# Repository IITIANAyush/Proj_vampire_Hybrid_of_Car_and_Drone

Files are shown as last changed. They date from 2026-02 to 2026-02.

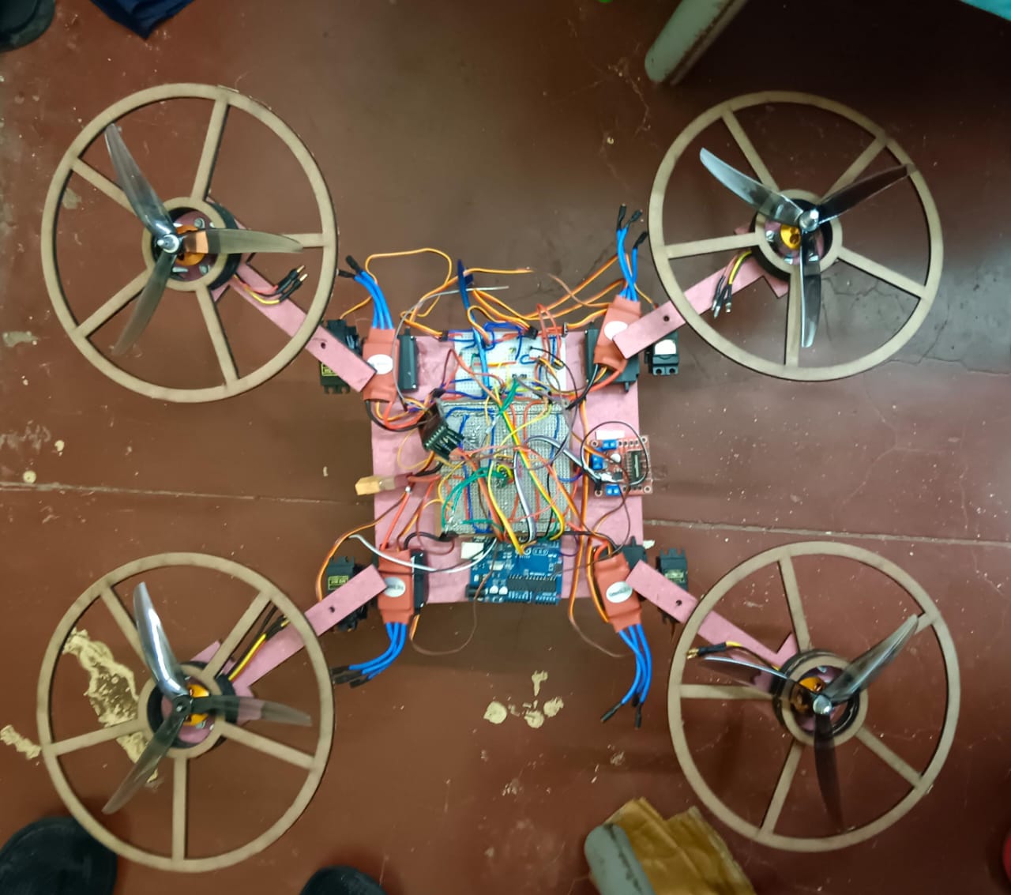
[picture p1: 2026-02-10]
Media/Assembly/Assembly_in_Drone_Mode2.jpg

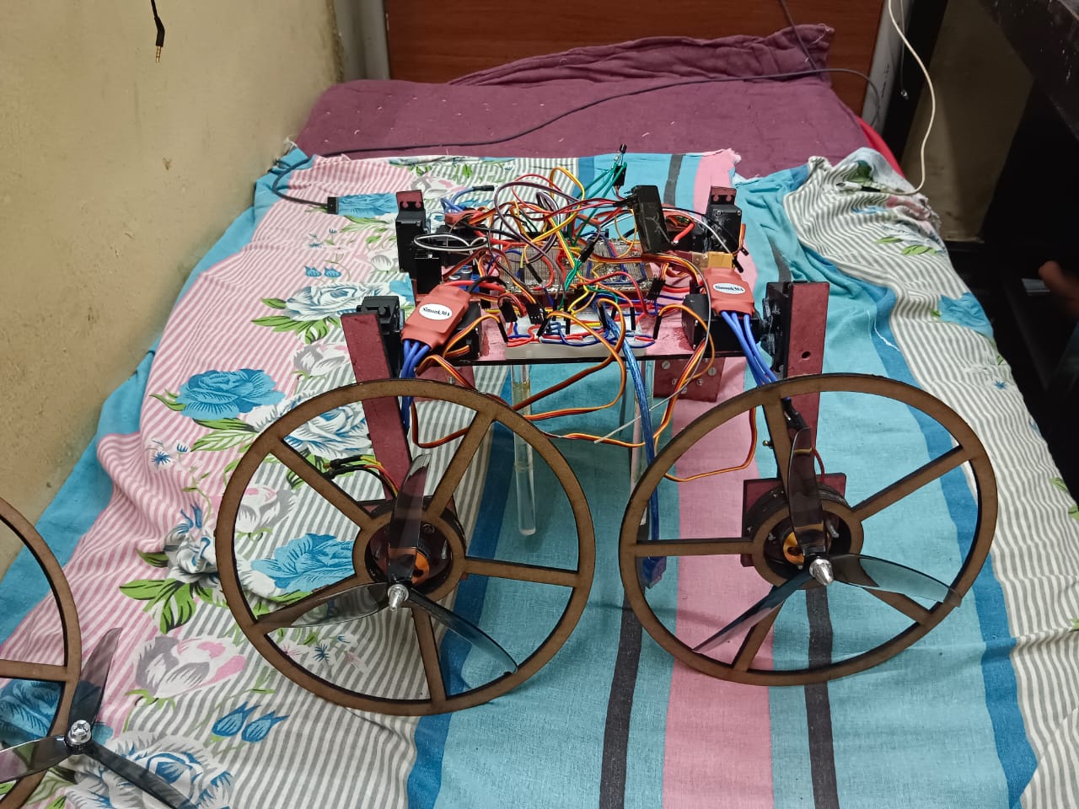
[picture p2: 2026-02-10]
Media/Assembly/Assembly_in_car_mode2.jpg

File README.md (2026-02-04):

# 🚀 Transformable Aerial–Ground Robot  
### Institute Technical Summer Project (ITSP)

This project presents the design and development of a **hybrid robot capable of operating both as a ground vehicle and as a quadcopter drone**. The system mechanically transforms between driving and flying configurations using servo-actuated arms.

Inspired by research in **reconfigurable robotics** from leading institutions like MIT, this project explores **multi-modal mobility**, where a single robot can adapt its structure to traverse different terrains and environments.

---

## 🎯 Project Objectives

- Design a robot that can **drive on the ground and fly in the air**
- Develop a **mechanical transformation system**
- Integrate **aerial and ground mobility** into one platform
- Build a **low-cost student prototype** using accessible components

---

## 🧩 System Overview

| Subsystem | Description |
|---|---|
| 🛞 Ground Mobility | Differential drive wheel system using DC motors |
| 🚁 Aerial Mobility | Quadcopter propulsion using brushless motors + ESCs |
| 🔁 Transformation Mechanism | Servo-actuated rotating arms |
| 🎮 Control Unit | Arduino-based control system |
| 🔋 Power System | LiPo battery powering motors and control electronics |

---

## 🛠 Hardware Design

The robot frame and transformation mechanism were custom-designed and iterated through multiple prototypes.

**Key Mechanical Features**
- Rotating arms that reposition wheels into propeller arms
- Lightweight structural frame
- Integrated motor mounting system

📁 See `Hardware/3D_Models/` for CAD files  
📁 Assembly visuals available in `Hardware/Assembly_Images/`

---

## 🔌 Electronics System

The electronics architecture manages both locomotion modes and the transformation system.

**Main Components**
- Arduino Uno
- Brushless motors + ESCs
- DC drive motors
- Servo motors for transformation
- RF transmitter & receiver module

📁 Circuit diagrams → `Electronics/Circuit_Diagrams/`  
📁 Wiring layouts → `Electronics/Wiring_Layouts/`  
📁 Tinkercad designs → `Electronics/Tinkercad_Designs/`

---

## 💻 Software Architecture

The control software is divided by functional modules.

| Module | Function |
|---|---|
| Flight Controller | Stabilization and motor control for drone mode |
| Car Mode Control | Wheel motor control for ground movement |
| Mode Switching | Handles transformation between car and drone |
| ESC Calibration | Calibration routine for brushless ESCs |

📁 All Arduino programs are available in the `Software/` directory.

---

## 🔁 Transformation Mechanism

The robot transitions between modes using servo-driven arms:

**Car Mode ➝ Drone Mode**
1. Arms rotate outward  
2. Wheels reposition to become landing supports  
3. Propellers align for flight  

**Drone Mode ➝ Car Mode**
1. Arms fold inward  
2. Wheels align for ground contact  
3. Drive motors engage  

This allows the robot to adapt based on terrain and task requirements.

---

## 🧪 Simulations & Testing

Early-stage circuit and control logic were tested using simulation tools before hardware implementation.

📁 Simulation files available in `Simulations/`

---

## 🎥 Demonstrations

Project demonstration videos showing transformation and testing:

📁 `Media/Transformation_Videos/`

---

## 📘 Documentation

Complete design explanation and project presentation:

📁 `Documentation/ITSP_Presentation.pdf`

---

## ⚠️ Safety Notice

This is a student-built prototype. Flight tests were conducted in controlled environments with safety precautions. The system is not intended for commercial or outdoor autonomous operation.

---

## 👨‍🔬 Developed Under

**Institute Technical Summer Project (ITSP)**  
Student Engineering Research Initiative

---

## 📌 Future Improvements

- Autonomous stabilization using IMU + PID control  
- Lightweight composite frame  
- Automatic terrain-based mode switching  
- Onboard camera for aerial surveillance  

---

## 🤝 Acknowledgment

This project was inspired by ongoing research in **transformable and reconfigurable robotics**, demonstrating how adaptable robots can enhance mobility in complex environments.

---

**⭐ If you find this project interesting, consider starring the repository!**

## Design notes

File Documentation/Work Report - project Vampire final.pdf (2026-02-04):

# Work Report - project Vampire

## Ayush Bhaskar- Dawar Jyoti Deka -Rahul Singh- Aman Raj

## ** dropped ideas and discussions has not been included in work report

Our Project Vampire integrates advanced aerial dynamics with sophisticated terrestrial navigation, utilising a unique orientation mechanism to transition from a car-like structure to a drone. The design addresses complex challenges in part integration, circuit design, and microprocessor coordination, ensuring seamless operation across diverse environments.

15th May to 6th June -
a. Decided upon the project idea , decided and built the team started ideating on the design and Abstract.
b. Started the technical research , digged research papers and similar projects that other universities are working on and found resources relevant to our project.
c. Drew out a basic design and made a basic working CAD model of the Chassis,decided the components like strong Servos , BLDC Motors for propellers and DC motors for Wheels , decided to make it a two wheel drive bot and Arduino , Motor Driver and electronic Speed Controllers for its technical performance as a drone.
d. Decided and designed the systems of control and command, parallelly worked on the mathematical analysis of the forces , weight and torques that the parts of the decided model might face and decided the specs of the components (Both mechanical and electrical ) on the basis of that.

7th June to 13th June i.e June Second Week -
a. Decided the control system we will be using to control the vehicle. Flysky FSi6a transmitter- receiver set.
b. Designed simulations and circuit for arm motion in tinkercad.
c. An online calculator or simulator ecal , and rc plane online was used to calculate the thrust generated and other information.
d. Number of servos and deciding their orientation for arm movement.
e. Orderning of some electrical parts.
f. Code for arm rotation part ready with tests on real models.

14th June to 20th June i.e third Week-
a. 3d sample model of drone with motion study formed.(in videos section of link)
b. Code for drone and other functions are ready to be uploaded on respective electronic controllers.
c. Decided the material to be used for the drone body , and laser cut it .

d. Soldered the pcb board to form a power distribution board and installed sensor and arduino nano on it.

21st June to 27th June i.e fourth Week-
a. Used epoxy glue to stick servos and power distribution board to the main chassis.
b. Decided the structure of the arm , decided to use double layered wood, with a 4mm hole in the outer side and servo horn cut on the inner part to fix it with a servo motor.
c. Made the model and tested it with code.
d. Building all connections on a breadboard.

28th June to 4th July i.e fifth Week -
a. Discussion on stand.
b. Discussion on concentric motion of tyre and propeller with different driving motors and without interference.
c. Usage of acrylic rods as stand to reduce stress on servo while changing mode and protecting battery
d. Buying materials(wires, glue,ball bearing)

5th July to 11th July i.e sixth Week -
a. Discussion and brainstorming on creating concentric independent motion for tyre and propeller.
b. Laser cutting of sample parts which will be used as tyres.
c. Buying material for creating tyre and belt driven motion for tyre.

12th July to 18th July i.e seventh Week-
a. Finalizing the design and making a 3d model for the coaxial tyre system.
b. Working on a Work report for the final review meeting.

19th July to 20th July i.e eight Week-
a. Worked on work report.
b. Buying material for laser cutting the tyre with spokes and coaxial system to be used in vehicle.

The drive link with all screenshots , video of simulations, code, 3d models and bill : https://drive.google.com/drive/folders/1VQIHgKka7rpowqe24aDche_vBiRUvNMP?usp=share_li nk (https://drive.google.com/drive/folders/1VQIHgKka7rpowqe24aDche_vBiRUvNMP?usp=share_link)

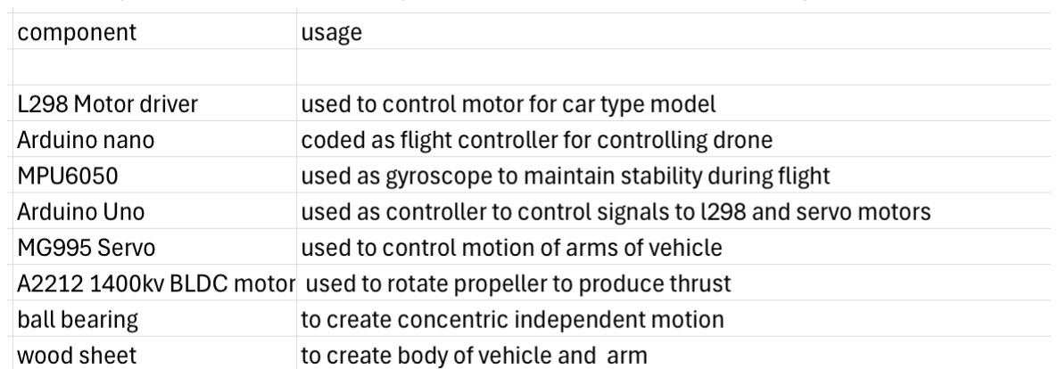
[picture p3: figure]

Some key components with key features to be used in our project are as listed

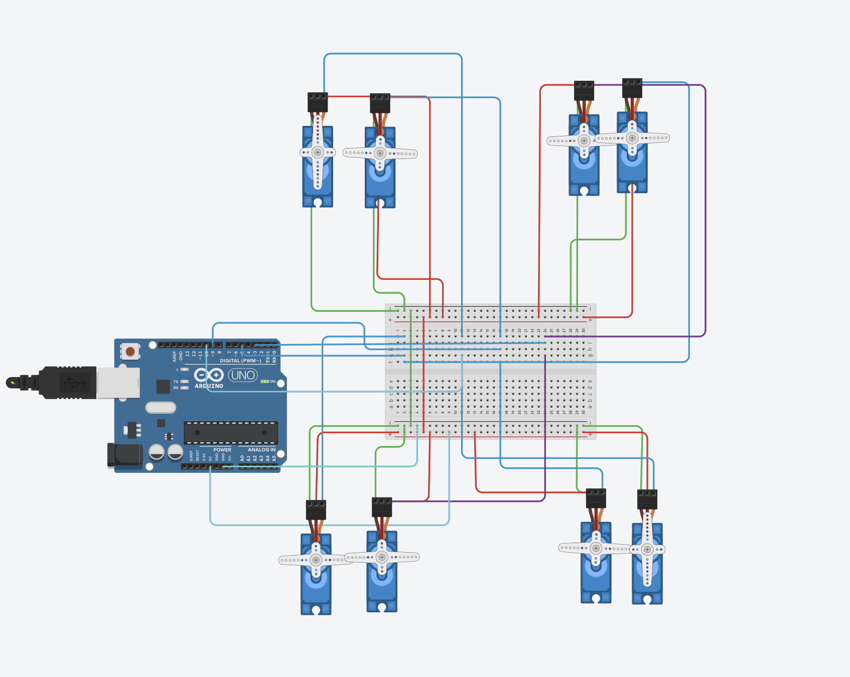
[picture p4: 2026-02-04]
Electronics/connection for controlling servo.png

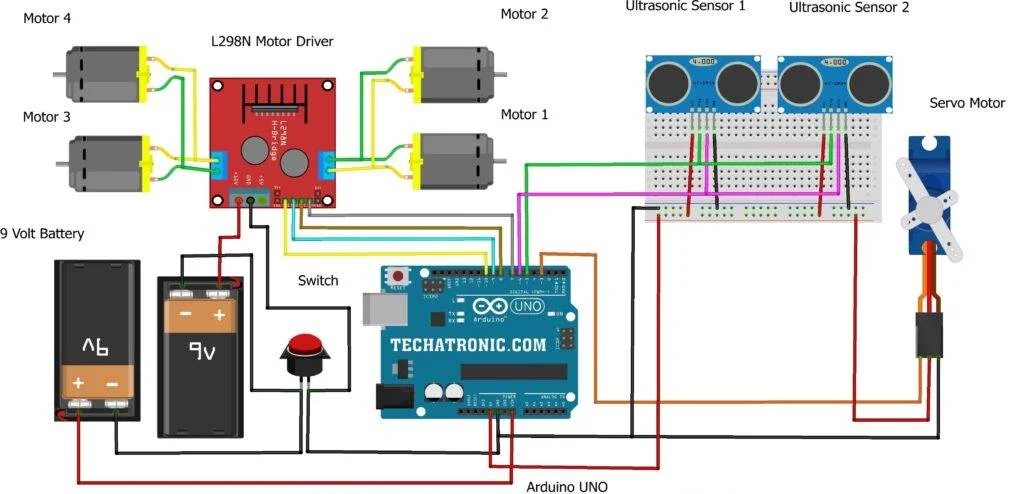
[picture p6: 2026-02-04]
Electronics/connection for driving motor using uno_ reference.webp

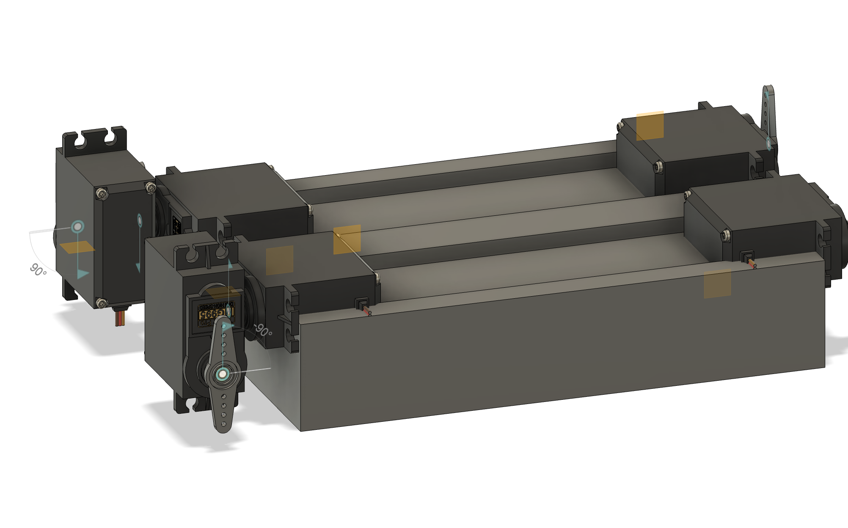
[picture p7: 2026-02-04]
Media/Simulation/deciding the servo orientation.png

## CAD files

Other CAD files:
Hardware/3d models/deciding the arm and placement of propellers with tyre rim.f3z
Hardware/3d models/deciding the servo orientation.f3z
Hardware/3d models/initial ideas and model.f3d
Hardware/3d models/wheel belt drive systum.f3z
Hardware/3d models/wheel_model v2.f3d

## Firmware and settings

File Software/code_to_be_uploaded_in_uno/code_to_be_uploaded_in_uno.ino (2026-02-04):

#include <Servo.h>

// Define servo objects
Servo chassy1;
Servo wheel1;
Servo chassy2;
Servo wheel2;

// Position variables
int poschassy1; // Position of servo of chassy
int poswheel1; // Position of servo of wheel

// State variables
bool previousstate = 0;
bool currentstate;

double ch1=6;
int a=8; int b=9;
 
double ch2=7;
int c=10; int d=11;

double ch6=12;
bool flag;

void setup() {
    Serial.begin(9600);
  pinMode(6,INPUT);
  pinMode(8,OUTPUT); pinMode(9,OUTPUT);
  
  pinMode(7,INPUT);
  pinMode(10,OUTPUT); pinMode(11,OUTPUT);

  pinMode(12,INPUT);
  
  // Set pin modes for servos
  pinMode(2, OUTPUT);
  pinMode(3, OUTPUT);
  pinMode(4, OUTPUT);
  pinMode(5, OUTPUT);

  // Set pin mode for switch

  // Detach all servos initially
  chassy1.detach();
  chassy2.detach();
  wheel1.detach();
  wheel2.detach();

  if(pulseIn(12,HIGH)<1100 && pulseIn(12,HIGH)>900){
    flag=0;
  }
  else{
    flag=1;
  }
  // Read initial switch state
  currentstate = flag;
  previousstate = currentstate;

  // Perform initial actions based on the initial state
  if (currentstate == LOW) { // Switch pressed, initial drone mode
    droneMode();
  } else { // Switch not pressed, initial car mode
    carMode();
  }

}

void loop() {
  // Read current switch state
    if(pulseIn(12,HIGH)<1100){
    flag=0;
  }
  else{
    flag=1;
  }
  currentstate = flag;

if(flag==1){
    ch1 = pulseIn(6,HIGH);
    ch2 = pulseIn(7,HIGH);

  if((ch1==0)&&(ch2==0))
  {     
  digitalWrite(a,LOW); digitalWrite(b,LOW);
  digitalWrite(c,LOW);digitalWrite(d,LOW);
  }

  else if((ch1>1530)&&(ch2>1530))
  {     
  digitalWrite(a,HIGH); digitalWrite(b,LOW);
  digitalWrite(c,LOW);digitalWrite(d,HIGH);    
  }

  else if((ch1>1530)&&(ch2<1460))
  { 
   digitalWrite(a,HIGH); digitalWrite(b,LOW);
  digitalWrite(c,HIGH);digitalWrite(d,LOW);    
  }

  else if((ch1<1460)&&(ch2>1530))
  {     
  digitalWrite(a,LOW); digitalWrite(b,HIGH);
  digitalWrite(c,LOW);digitalWrite(d,HIGH);
  }

  else if((ch1<1460)&&(ch2<1460))
  {  digitalWrite(a,LOW); digitalWrite(b,HIGH);
  digitalWrite(c,HIGH);digitalWrite(d,LOW);
  
  }

else
{     
 digitalWrite(a,LOW); digitalWrite(b,LOW);
 digitalWrite(c,LOW);digitalWrite(d,LOW);
}
  }

  // Detect state change
if (currentstate != previousstate) {
    previousstate = currentstate;

    // Perform actions based on the new state
    if (currentstate == 0) { // Switch pressed, go to drone mode
      droneMode();
    } else { // Switch not pressed, go to car mode
      carMode();
      
     }
  }
}

void droneMode() {
  // Attach servos
  chassy1.attach(2);
  wheel1.attach(3);
  chassy2.attach(4);
  wheel2.attach(5);

  // Perform actions for drone mode
  for (poswheel1 = 90; poswheel1 > 0; poswheel1--) {
    wheel1.write(poswheel1);
    wheel2.write(180 - poswheel1);
    delay(20);
  }
  for (poschassy1 = 90; poschassy1 < 135; poschassy1++) {
    chassy1.write(poschassy1);
    chassy2.write(180 - poschassy1);
    delay(20);
  }
  for (poswheel1 = 0; poswheel1 < 45; poswheel1++) {
    wheel1.write(poswheel1);
    wheel2.write(180 - poswheel1);
    delay(20);
  }
  for (poschassy1 = 135; poschassy1 <= 180; poschassy1++) {
    chassy1.write(poschassy1);
    chassy2.write(180 - poschassy1);
    delay(20);
  }

  // Detach servos
  chassy1.detach();
  chassy2.detach();
  wheel1.detach();
  wheel2.detach();
}

void carMode() {
  // Attach servos
  chassy1.attach(2);
  wheel1.attach(3);
  chassy2.attach(4);
  wheel2.attach(5);

  // Perform actions for car mode
  for (poschassy1 = 180; poschassy1 > 135; poschassy1--) {
    chassy1.write(poschassy1);
    chassy2.write(180 - poschassy1);
    delay(20);
  }
  for (poswheel1 = 45; poswheel1 > 0; poswheel1--) {
    wheel1.write(poswheel1);
    wheel2.write(180 - poswheel1);
    delay(20);
  }
  for (poschassy1 = 135; poschassy1 > 90; poschassy1--) {
    chassy1.write(poschassy1);
    chassy2.write(180 - poschassy1);
    delay(20);
  }
  for (poswheel1 = 0; poswheel1 < 90; poswheel1++) {
    wheel1.write(poswheel1);
    wheel2.write(180 - poswheel1);
    delay(20);
  }

  // Detach servos
  chassy1.detach();
  chassy2.detach();
  wheel1.detach();
  wheel2.detach();

}

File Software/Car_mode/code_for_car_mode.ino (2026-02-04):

// Pin definitions
const int ch1Pin = 2; // CH1 signal pin
const int ch2Pin = 3; // CH2 signal pin
const int ENA = 5;
const int ENB = 6;
const int IN1 = 7;
const int IN2 = 8;
const int IN3 = 9;
const int IN4 = 10;

// Variables to store pulse duration
volatile int ch1Value = 1500;
volatile int ch2Value = 1500;

void setup() {
  // Initialize motor control pins
  pinMode(ENA, OUTPUT);
  pinMode(ENB, OUTPUT);
  pinMode(IN1, OUTPUT);
  pinMode(IN2, OUTPUT);
  pinMode(IN3, OUTPUT);
  pinMode(IN4, OUTPUT);

  // Initialize receiver input pins
  pinMode(ch1Pin, INPUT);
  pinMode(ch2Pin, INPUT);

  // Attach interrupts for channel signals
  attachInterrupt(digitalPinToInterrupt(ch1Pin), ch1ISR, CHANGE);
  attachInterrupt(digitalPinToInterrupt(ch2Pin), ch2ISR, CHANGE);
}

void loop() {
  // Map receiver values to motor speed and direction
  int speed = map(ch1Value, 1000, 2000, -255, 255);
  int turn = map(ch2Value, 1000, 2000, -255, 255);

  // Calculate motor speeds
  int leftMotorSpeed = speed + turn;
  int rightMotorSpeed = speed - turn;

  // Constrain motor speeds to -255 to 255
  leftMotorSpeed = constrain(leftMotorSpeed, -255, 255);
  rightMotorSpeed = constrain(rightMotorSpeed, -255, 255);

  // Control motors
  setMotorSpeed(leftMotorSpeed, rightMotorSpeed);

  delay(20);
}

void setMotorSpeed(int leftSpeed, int rightSpeed) {
  // Left motor control
  if (leftSpeed >= 0) {
    digitalWrite(IN1, HIGH);
    digitalWrite(IN2, LOW);
    analogWrite(ENA, leftSpeed);
  } else {
    digitalWrite(IN1, LOW);
    digitalWrite(IN2, HIGH);
    analogWrite(ENA, -leftSpeed);
  }

  // Right motor control
  if (rightSpeed >= 0) {
    digitalWrite(IN3, HIGH);
    digitalWrite(IN4, LOW);
    analogWrite(ENB, rightSpeed);
  } else {
    digitalWrite(IN3, LOW);
    digitalWrite(IN4, HIGH);
    analogWrite(ENB, -rightSpeed);
  }
}

// Interrupt Service Routine for CH1
void ch1ISR() {
  static unsigned long startTime;
  if (digitalRead(ch1Pin) == HIGH) {
    startTime = micros();
  } else {
    ch1Value = micros() - startTime;
  }
}

// Interrupt Service Routine for CH2
void ch2ISR() {
  static unsigned long startTime;
  if (digitalRead(ch2Pin) == HIGH) {
    startTime = micros();
  } else {
    ch2Value = micros() - startTime;
  }
}
